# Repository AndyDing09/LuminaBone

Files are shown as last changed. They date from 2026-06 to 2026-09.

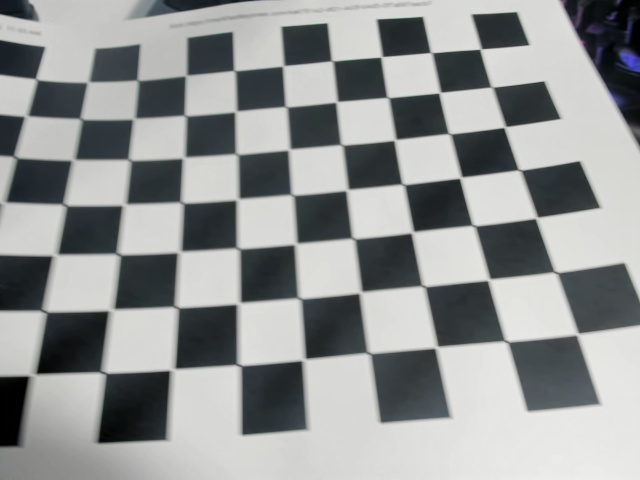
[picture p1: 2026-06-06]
calibration/calib_images/calib_034.jpg

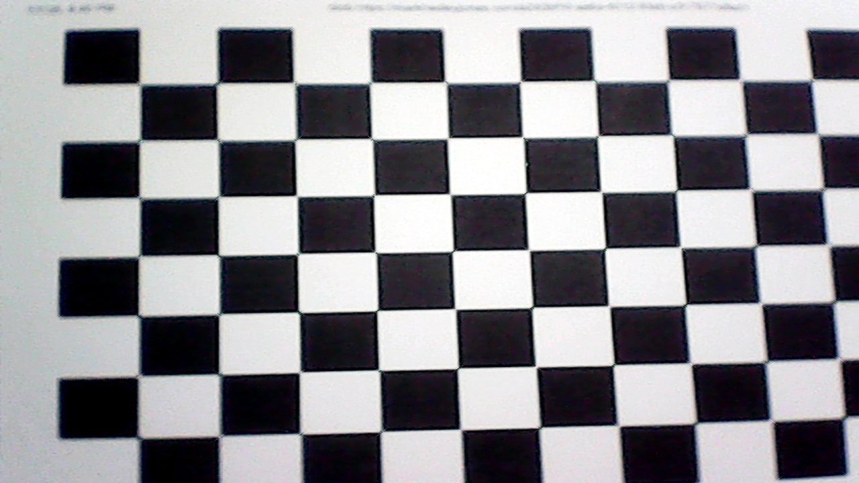
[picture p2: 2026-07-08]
calibration/calib_images_1280x720/calib_1280x720_20260707_221627_039.jpg

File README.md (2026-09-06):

# LuminaBone

Endoscope-based bone reconstruction and validation against CT ground truth,
using retroreflective marker tracking for depth/positioning.

## Status (marker-pipeline branch)

This branch is exploratory/diagnostic — several results are flagged
unreliable and documented as such rather than hidden. Read this before
trusting any numbers:

- **Reliable:** marker pixel-coordinate detection (all shots); marker
  distance from lens for shot_011 (CT + PnP ground truth).
- **Not reliable:** far-field photometric depth (`marker_depth_slides.py`)
  — inverted vs. CT at shot_011 (corr −0.92); everything downstream of it
  for shots 10/12/13/14/15 inherits that inversion.
- **Built but blocked:** near-field Lambertian depth solver
  (`nearfield_lambertian.py`) and LED calibration (`led_calibration.py`) —
  the physically-correct depth path, waiting on mirror-ball/white-card
  calibration captures that don't exist yet.
- **Registration (endoscope patches vs. CT spine):** automatic
  similarity-ICP registration of 17 reconstructed patches does **not**
  correctly localize them — patches drape onto the same region rather than
  spreading to their true anatomical sites, so the ~1.9 mm "accuracy"
  figure is an artifact, not a real accuracy measurement. A valid study
  needs landmark correspondences or fiducial markers.

## Repo layout

- `marker_pipeline/` — tracker detection → marker depth → CT-distance
  scripts, with a detailed status table in its own README.
- `registration/` — endoscope-to-CT ICP registration, accuracy report,
  and Slicer/photogrammetry helpers.
- `scripts/` — shared `calibration/`, `experiments/`, and `reconstruction/`
  code (e.g. `bone_depth_batch.py`, the far-field core dependency).
- `presentations/` — triangulation slide deck (PDF/PPTX).
- `viewer_checks/` — sanity-check renders of reconstructed models.
- `tools/` — misc utilities (e.g. `rclone.exe`).

## Open next steps

1. Capture LED calibration targets (mirror ball + matte white card) to
   unblock the near-field depth solver.
2. Resolve focal length ambiguity (fx 519 vs. 794) to remove the ~1.5×
   depth-scale uncertainty.
3. Add landmark or fiducial-based anchoring so endoscope-vs-CT accuracy
   can be measured honestly instead of via drape-fitting ICP.

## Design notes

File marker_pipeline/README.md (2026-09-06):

# marker_pipeline

Everything from the tracker → marker-depth → CT-distance work, grouped in one
place. Read the **status** column first: it says what you can trust.

## TL;DR — what is actually reliable

| Result | Trust it? |
|---|---|
| Marker **pixel coordinates** (all shots) | ✅ Yes — direct detection |
| Marker **distance from lens, shot_011** | ✅ Yes — CT ground truth + PnP (4≈33, 1≈51, 3≈53 mm*) |
| Marker **relative depth** (`marker_depth_slides`) | ❌ No — far-field model, came out **inverted** vs CT at shot_011 |
| Marker **distance, shots 10/12/13/14/15** | ❌ No — photometric only, no CT to validate (inherits the inversion) |

\* absolute values carry a ~1.5× uncertainty because the focal length is still unresolved (fx 519 vs 794).

**Only shot_011 has CT, and there the far-field depth is inverted.** So the depth
numbers are for locating/plotting markers, not for trustworthy depth. The real
depth fix (near-field solve) is built but **blocked on calibration captures**.

## Files — used vs. not

| File | Does | Status |
|---|---|---|
| `detect_trackers.py` | Finds the retroreflective markers, per image + consolidated per shot | ✅ **USED, reliable** |
| `marker_depth_slides.py` | Per-shot far-field photometric depth + the triangulation-style slides with (x,y,z) | ⚠️ **USED for x,y + slides; depth is far-field & inverted** |
| `marker_distances.py` | Lens-to-marker distance: CT+PnP for shot_011, photometric (flagged) for the rest | ✅ **USED** (shot_011 reliable; rest flagged UNRELIABLE) |
| `apply_ct_shot011.py` | Anchors shot_011 depth to CT; **documents** that the far-field depth is inverted | ⚠️ **USED as a diagnostic**, not a trustworthy correction |
| `ct_correct_depth.py` | Affine-z / tilt-plane correction helpers (self-test passes) | ✅ tool reliable; its *input* (far-field depth) is the weak link |
| `led_calibration.py` | Quéau et al. 2017 LED calibration (position/direction/µ/intensity) | 🚧 **BUILT, NOT USED** — needs mirror-ball + white-card captures that don't exist yet |

### Shared infrastructure (NOT moved — lives in `../scripts/reconstruction/`)
| File | Role | Status |
|---|---|---|
| `bone_depth_batch.py` | Far-field photometric-stereo core + image/calibration helpers | dependency (has its own pre-existing uncommitted edits) |
| `nearfield_lambertian.py` | Near-field solver; **upgraded this session to require a solved `led_calibration.json`** (no assumed geometry) | 🚧 **the intended real depth path**, blocked until calibration exists |

## How to reproduce (run order)

```bash
# from marker_pipeline/
python detect_trackers.py ../Data_collection/shots/shot_*/led*.png \
       --outdir ../tracker_outputs --csv ../tracker_outputs/trackers.csv
python marker_depth_slides.py                 # per-shot depth slides + marker_depths.csv
python marker_distances.py                    # lens-to-marker distances (shots 10-15)
python apply_ct_shot011.py                    # shot_011 CT anchor (diagnostic)

# validation (no data needed):
python ct_correct_depth.py --selftest
python led_calibration.py  --selftest
```

Outputs land in `../depth_outputs/marker_depth_slides/` and `../tracker_outputs/`.

## The one path to trustworthy depth (currently blocked)
1. Capture calibration targets: a **mirror ball** (~10 poses/LED) and a **matte
   white card** (~3–5 tilts/LED).
2. `led_calibration.py` → writes `calibration/led_calibration.json`.
3. `nearfield_lambertian.py` re-solves depth with the real light model (no bowl,
   no inversion).
4. Anchor the result to CT with `ct_correct_depth.py`.

Also worth doing: resolve the focal length (photograph a known-size object at a
known distance) to kill the 1.5× absolute-scale ambiguity.

## Key caveats discovered
- **CT is in the CT scanner's frame, not the camera frame** — you must PnP-align
  before comparing depth. Raw-axis comparison is meaningless.
- **P3P with 3 points is ambiguous** (up to 4 poses); we disambiguate with the
  confirmed physical fact that *marker 4 is closest*.
- With that pose, the far-field photometric depth is **anti-correlated with CT
  (corr −0.92)** at shot_011 — i.e. inverted. That is the headline finding.

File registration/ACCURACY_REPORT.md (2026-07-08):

# Endoscope-vs-CT accuracy: what the registration actually shows

## What I did
Registered all 17 endoscope reconstructions (`loc01–17`) to the CT spine
(`ct_spine.stl`, a lumbar+sacrum segment, mm coordinates) using automatic
similarity ICP (rotation + translation + uniform scale), with centroid
initialization, a realistic scale prior, and rotation restarts. Outputs are in
`reg_out/`: each aligned patch, a combined model (`combined_CT_plus_17.ply`),
per-patch metrics (`accuracy_summary.csv`), and the overlay (`accuracy_overlay.png`).

## The honest result: automatic registration did NOT place the patches correctly
- **12 of 17** patches got a plausible scale (~0.07 mm/px) and ~1.9 mm median
  surface distance — which *looks* like a good accuracy number.
- **But the overlay shows they all piled onto the same region of the bone**,
  stacked as flat cards, instead of spreading to the 17 different spots where the
  photos were actually taken. So the low distance is a **draping artifact**: a
  bumpy patch laid flat against a bumpy surface always sits ~2 mm off, *wherever*
  you put it. It is not a measure of reconstruction accuracy.
- **5 of 17** (loc07, 09, 10, 11, 14) collapsed to scale ≈ 0 — the scale-ICP
  shrank the patch to a point to trivially minimise distance. Flagged SUSPECT.

The uniformity is the tell: median deviation across the 12 "OK" patches is
1.86 mm with a standard deviation of only 0.17 mm. Genuinely-registered patches
at 17 different anatomical sites would not all score the same.

## Why this happens (not fixable by better ICP)
Each endoscope view is a small, nearly-flat brightness-relief patch; the CT is a
whole 232 mm multi-vertebra segment. With no point correspondences and no known
probe pose, a flat patch can rest on many places with equally low residual, and
its scale is unconstrained. ICP therefore cannot recover the *true* location — it
finds *a* low-distance drape, not the *correct* one.

## The one real quantitative finding
The recovered scales for the 12 non-degenerate patches cluster at
**0.070 ± 0.012 mm/px**. Consistent scale across independent views is expected if
the endoscope working distance was roughly constant — a believable internal
cross-check on the reconstruction pipeline. (Note: the pipeline's own
`depth_estimates.csv` implies ~0.047 mm/px for the depth axis; the ~0.07 in-plane
value is the same order, differing because depth and in-plane were scaled
separately.)

## What a valid accuracy study needs
To actually measure "how accurate is the endoscope reconstruction vs CT," each
patch must first be correctly located on the bone. That requires one of:
1. **Matched landmarks per patch** — 3–4 corresponding points (e.g. the through-
   holes/foramina visible in both the photo and the CT). The tools here
   (`landmark_register.py` + `icp_refine.py`) compute this in closed form and
   report a real error, but placing the points needs someone who knows where each
   shot was taken.
2. **CT-visible fiducial markers** (metal beads) placed on the specimen before
   scanning, appearing in both modalities.
3. **Recorded probe poses** at capture time.

Once any patch is correctly anchored (the loc03 foramina are the best candidate),
the residual surface distance at that site becomes a *true* reconstruction-accuracy
number, and the same can be repeated for the rest.

## Files
- `reg_out/accuracy_overlay.png` — shows the piling-up problem
- `reg_out/accuracy_summary.csv` — per-patch scale, deviation, reliability
- `reg_out/combined_CT_plus_17.ply` — CT + all patches, viewable in Slicer
- `reg_out/locNN_reg.ply` — individual aligned patches

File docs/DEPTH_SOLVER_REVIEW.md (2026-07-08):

# Depth Estimate Solver Review

## Source Of Truth

The current depth estimate solver is in `bone_depth_batch.py`. The exact solve
path is:

1. `process_location()`
2. `solve_luminance()`
3. `balance_exposure()`
4. `photometric_stereo()`
5. `normals_to_depth()`
6. `integrate_frankot_chellappa()`

`bone_depth_values.py`, `depth_recompute.py`, and `make_triangulation_slides.py`
reuse that same solver. Scripts with `allon` in the name use the older
single-image brightness-to-depth approximation from `endoscope_depth.py`; those
are useful for quick colored meshes, but they are not the main three-light depth
estimate.

## Inputs

Each location is expected to have four photos:

- `pN-1`: all LEDs on, used as a visual/color reference
- `pN-2`: right LED only
- `pN-3`: upper LED only
- `pN-4`: left LED only

The depth solve uses only the three single-LED photos. The all-on photo does not
drive the photometric-stereo solve.

## Calculation Flow

First, each single-LED RGB image is converted to linear luminance. The code
undoes sRGB gamma, converts RGB to a brightness channel, removes specular glints,
and balances exposure by dividing each light image by its median brightness.
This matters because photometric stereo assumes brightness differences come from
surface orientation, not camera auto-exposure or shiny highlights.

Next, the solver builds a light-direction matrix `L`. Each row is a known unit
light vector from `SINGLE_LED_AZIMUTH_DEG` and `LIGHT_ELEVATION_DEG`.

For every pixel, the three observed brightnesses form:

```text
L @ g = I
```

where `I` is the pixel brightness under the three LEDs and `g` is the unknown
albedo-scaled normal. With three lights, the code uses an exact inverse:

```text
g = inverse(L) @ I
```

Then:

```text
albedo = norm(g)
normal = g / albedo
```

After normals are estimated, `normals_to_depth()` converts them into depth
gradients. With the repo's convention, larger depth means farther from the
camera:

```text
d(depth)/d(col) = +nx / nz
d(depth)/d(row) = -ny / nz
```

Finally, `integrate_frankot_chellappa()` solves for the depth map whose
gradients best match those two gradient fields. It does this in the frequency
domain with an FFT Poisson solve. The result is a relative depth map.

## Units

The native output is relative depth in working-resolution pixel units. The
relative relief shape is meaningful, but the absolute physical height is not
known from photometric stereo alone.

The scripts now report inch-scaled relief using:

```text
inches_per_pixel = FIELD_WIDTH_IN / image_width_px
relief_in = relief_px * inches_per_pixel
```

This is only physically correct if `FIELD_WIDTH_IN` is the measured real width
of the photographed area. The default keeps the previous 30 mm placeholder,
converted to inches, so update it before treating the inch values as true.

## Review Notes

- The main photometric-stereo math is internally consistent.
- The sign convention is depth-away-from-camera; 3D plots negate depth so bone
  protrusions point upward/toward the viewer.
- The strongest uncertainty is absolute scale. `LIGHT_ELEVATION_DEG` changes
  vertical relief, and `FIELD_WIDTH_IN` converts pixel relief to physical units.
- The `pN-3` upper light is calibrated as an upper-right light, not a pure top
  light. That is already reflected in `SINGLE_LED_AZIMUTH_DEG`.
- The older `allon` mesh scripts use a simpler inverse-square brightness model.
  Use the photometric-stereo outputs for the best available depth relief.

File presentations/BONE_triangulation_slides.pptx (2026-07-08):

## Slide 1

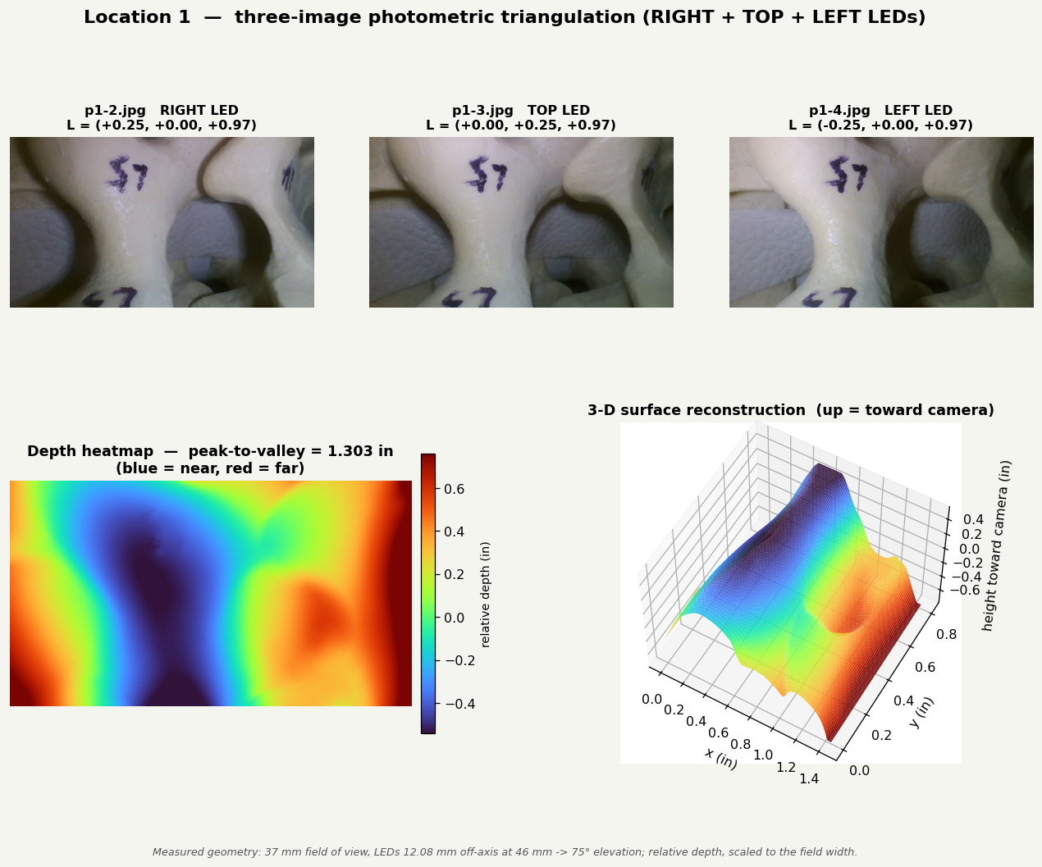
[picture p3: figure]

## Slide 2

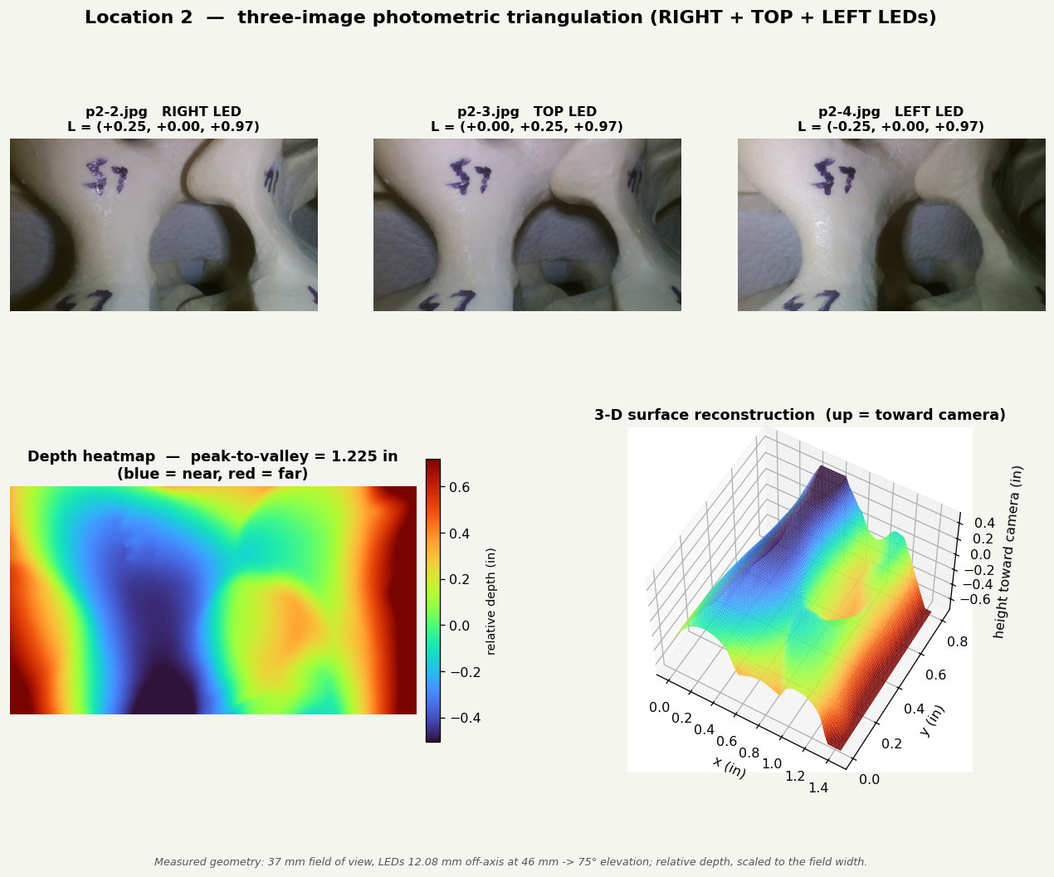
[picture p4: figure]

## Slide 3

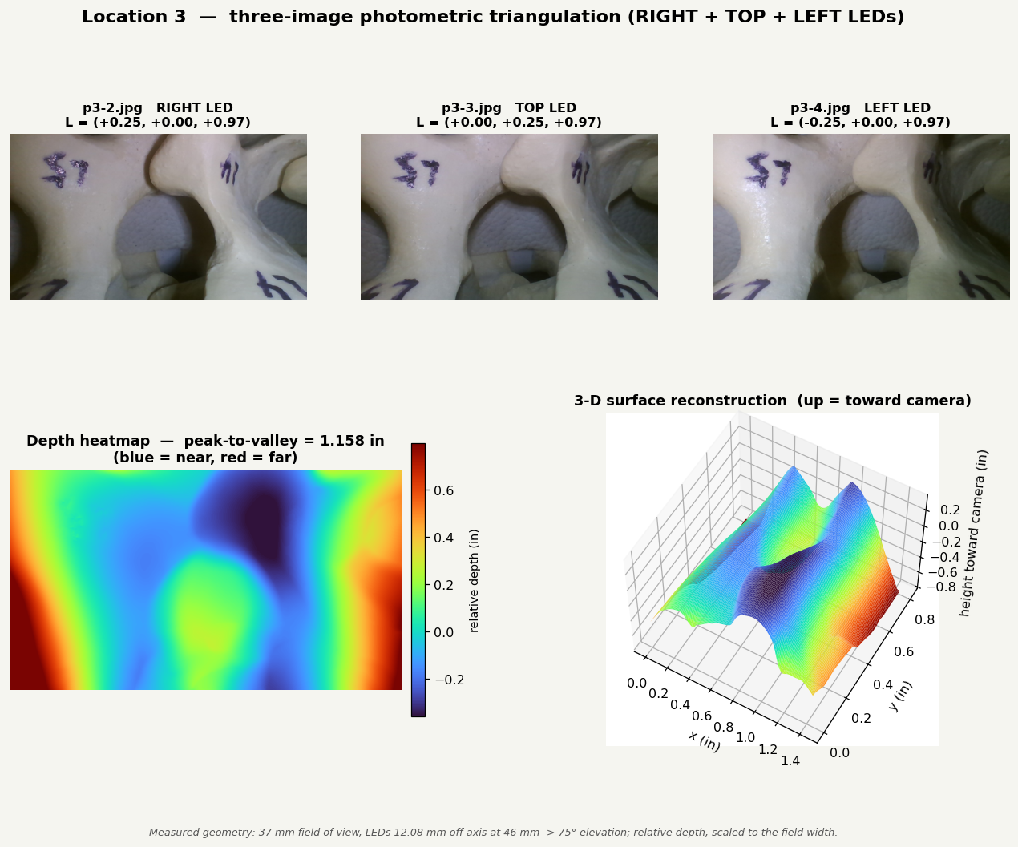
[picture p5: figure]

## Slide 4

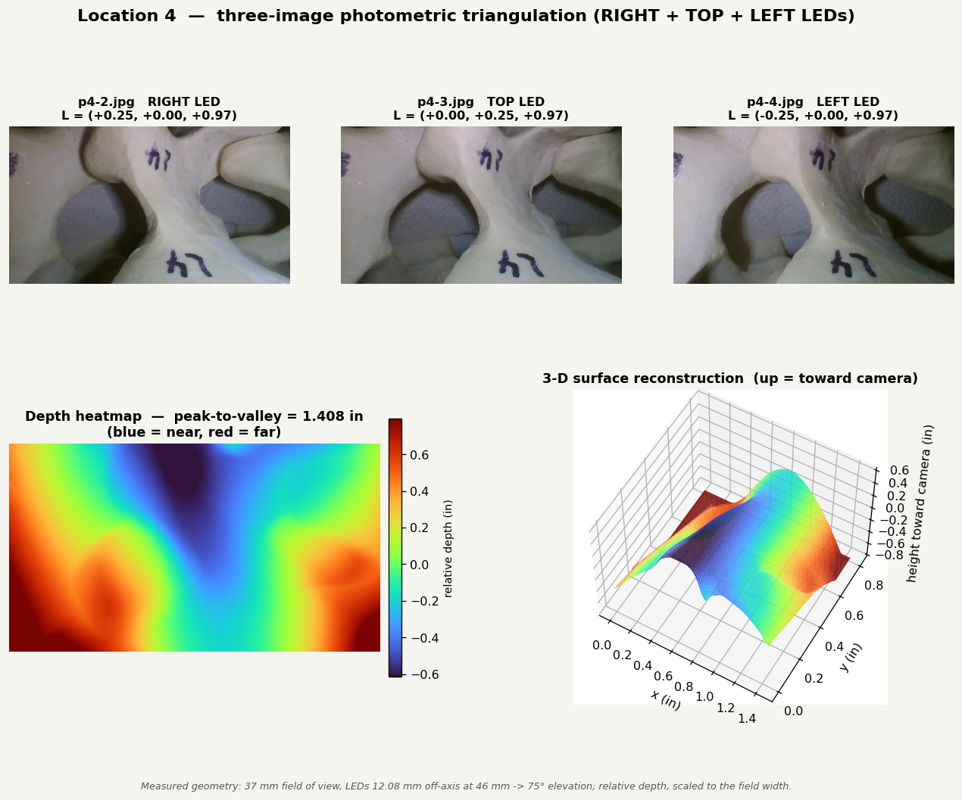
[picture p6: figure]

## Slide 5

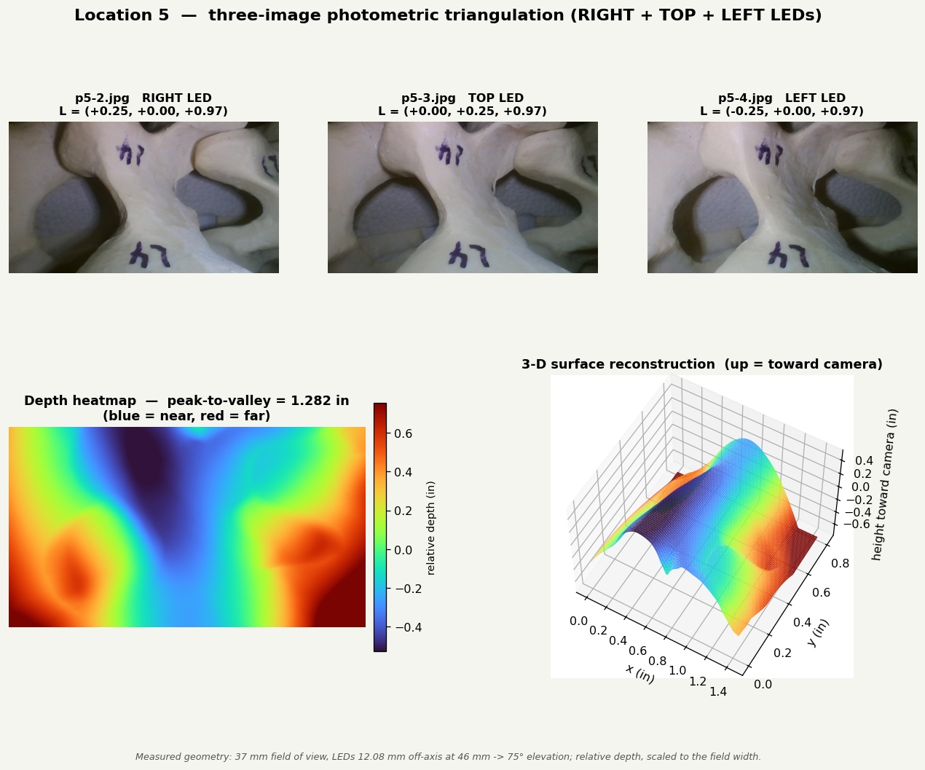
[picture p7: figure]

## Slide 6

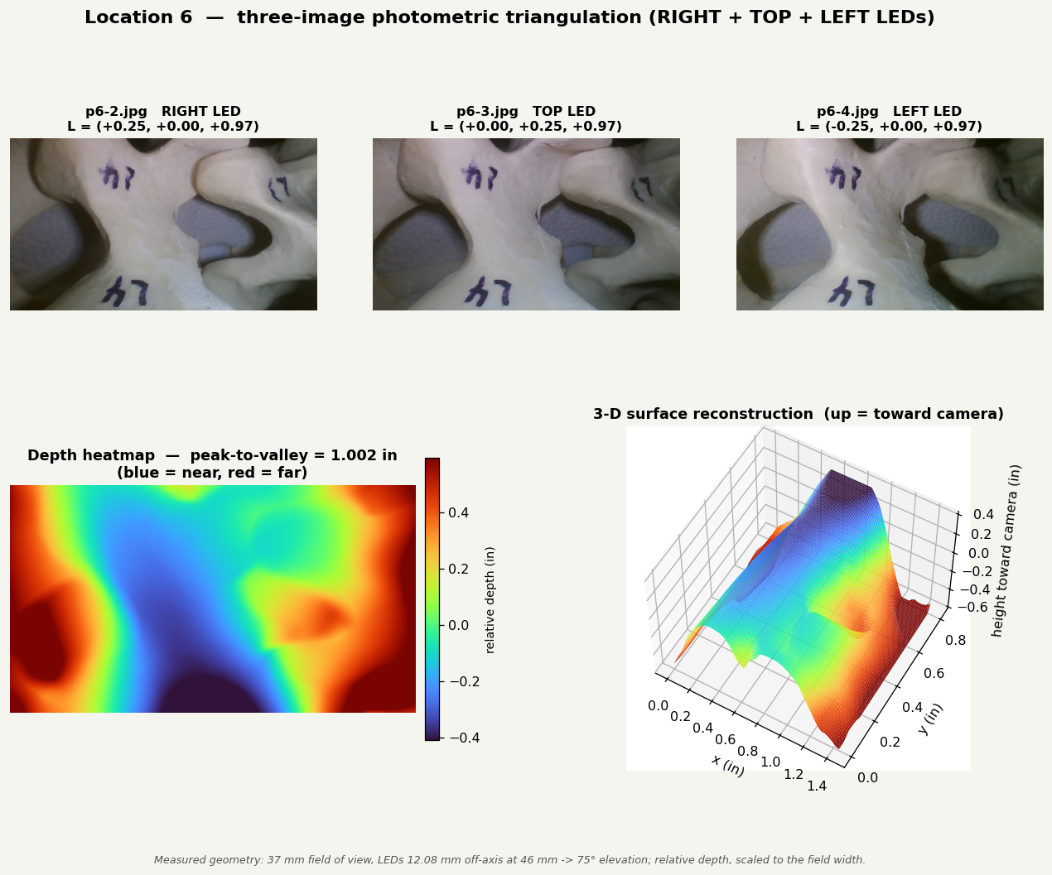
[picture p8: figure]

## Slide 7

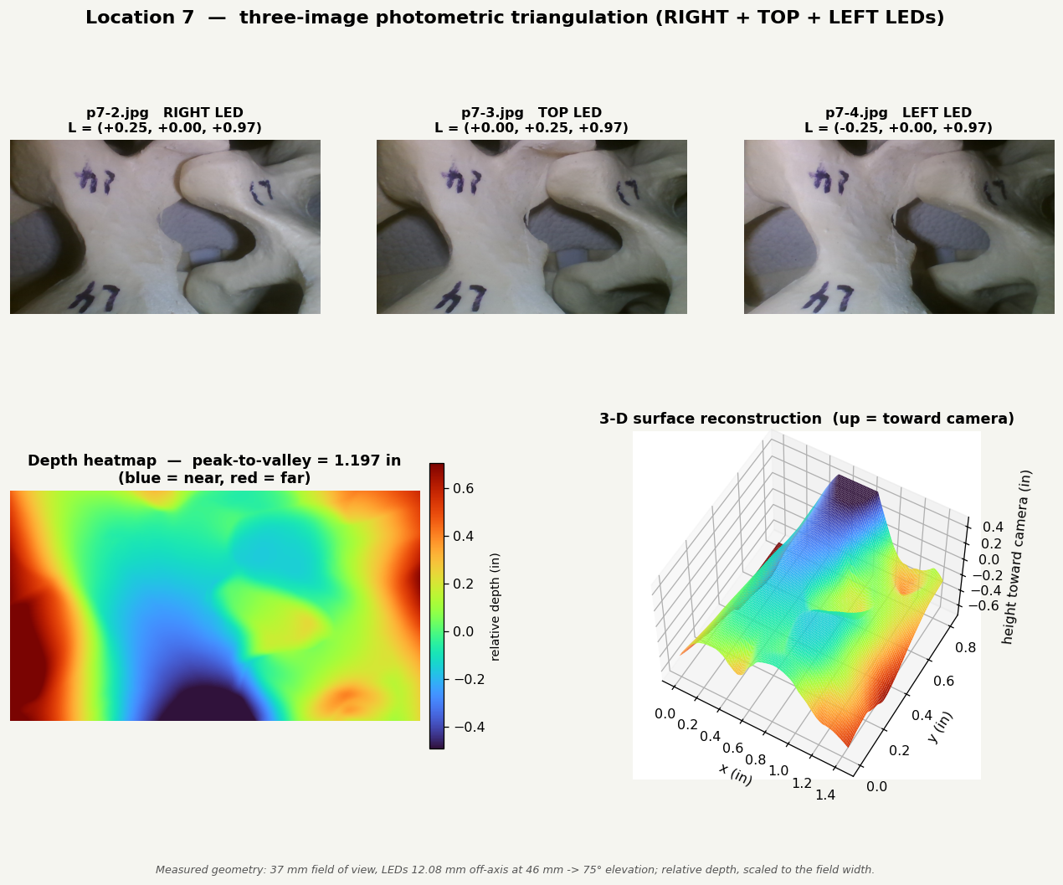
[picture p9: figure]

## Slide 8

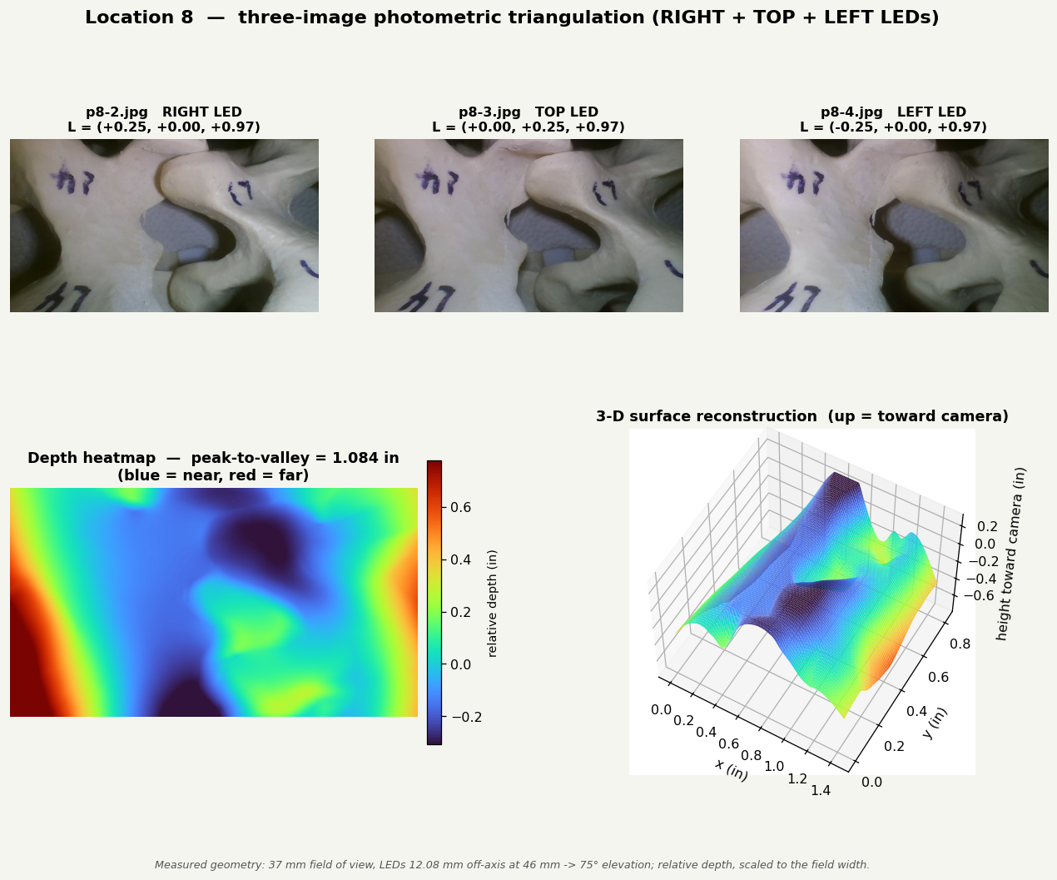
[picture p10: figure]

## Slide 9

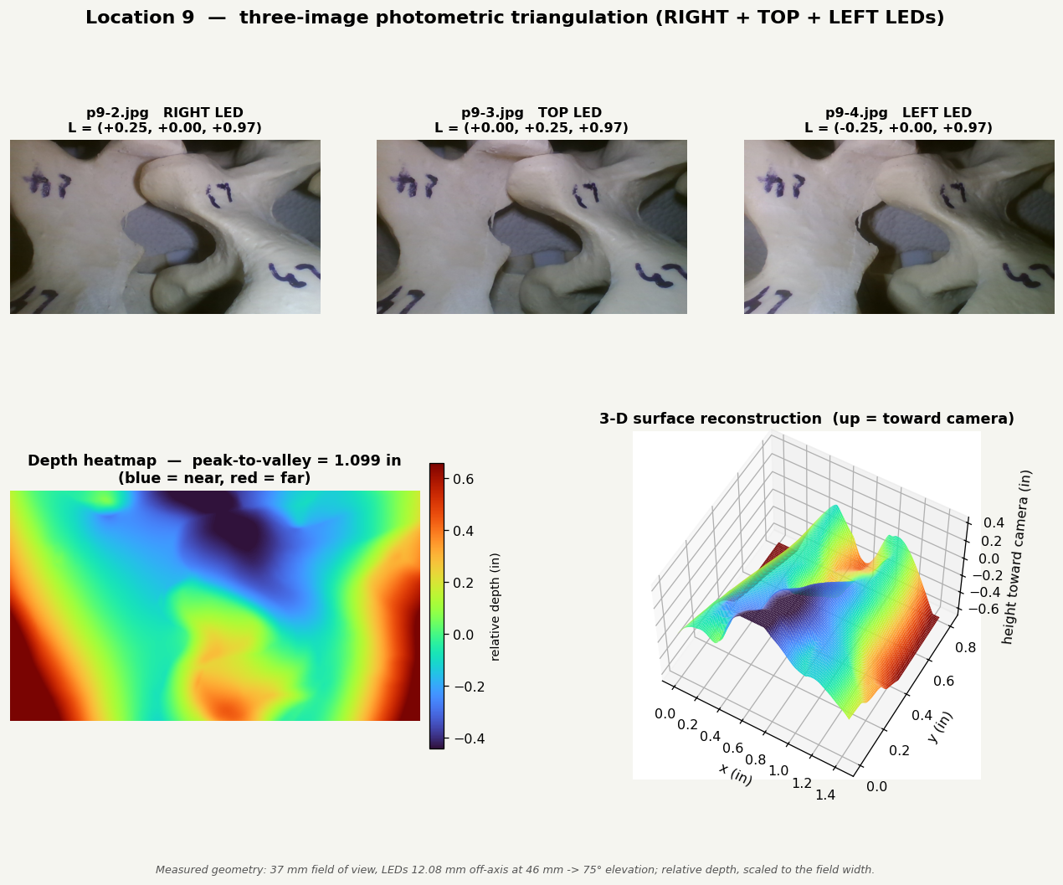
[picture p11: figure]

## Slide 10

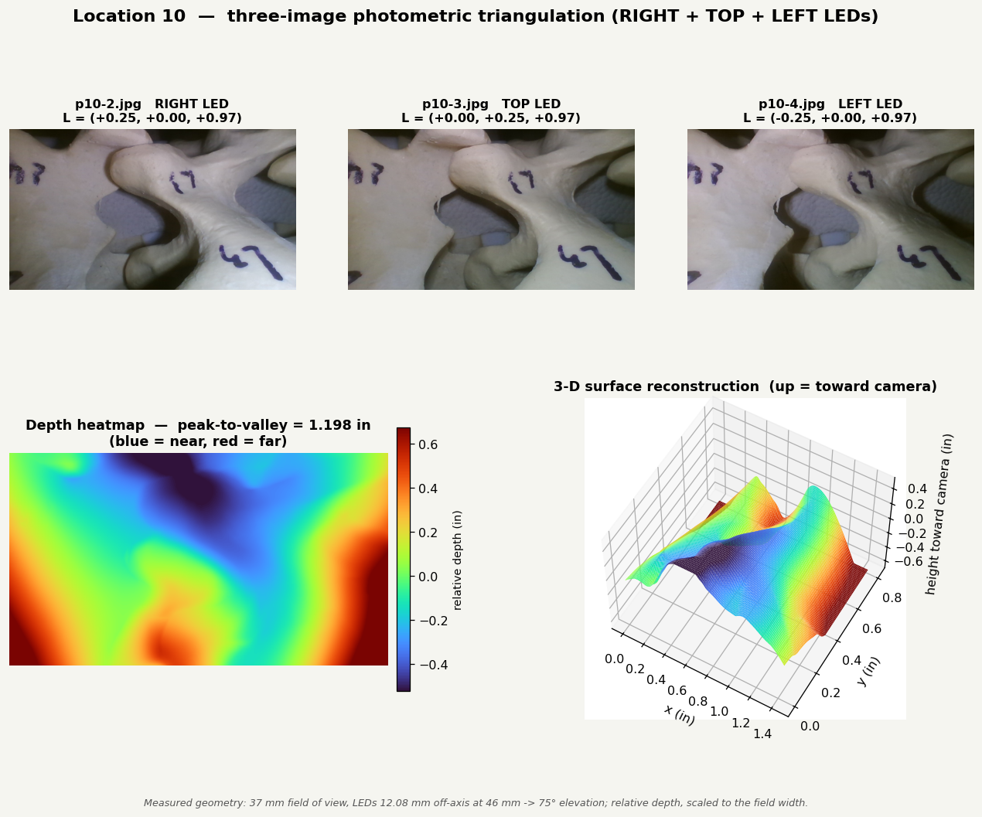
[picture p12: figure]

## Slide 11

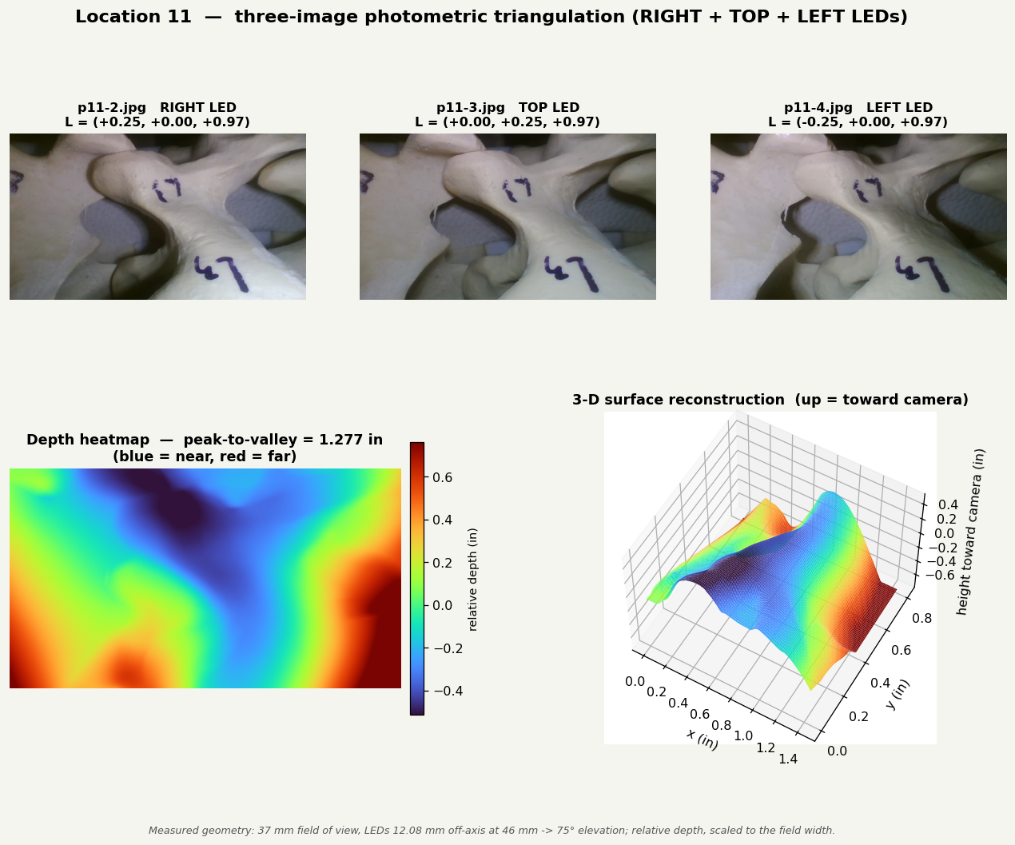
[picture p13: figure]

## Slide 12

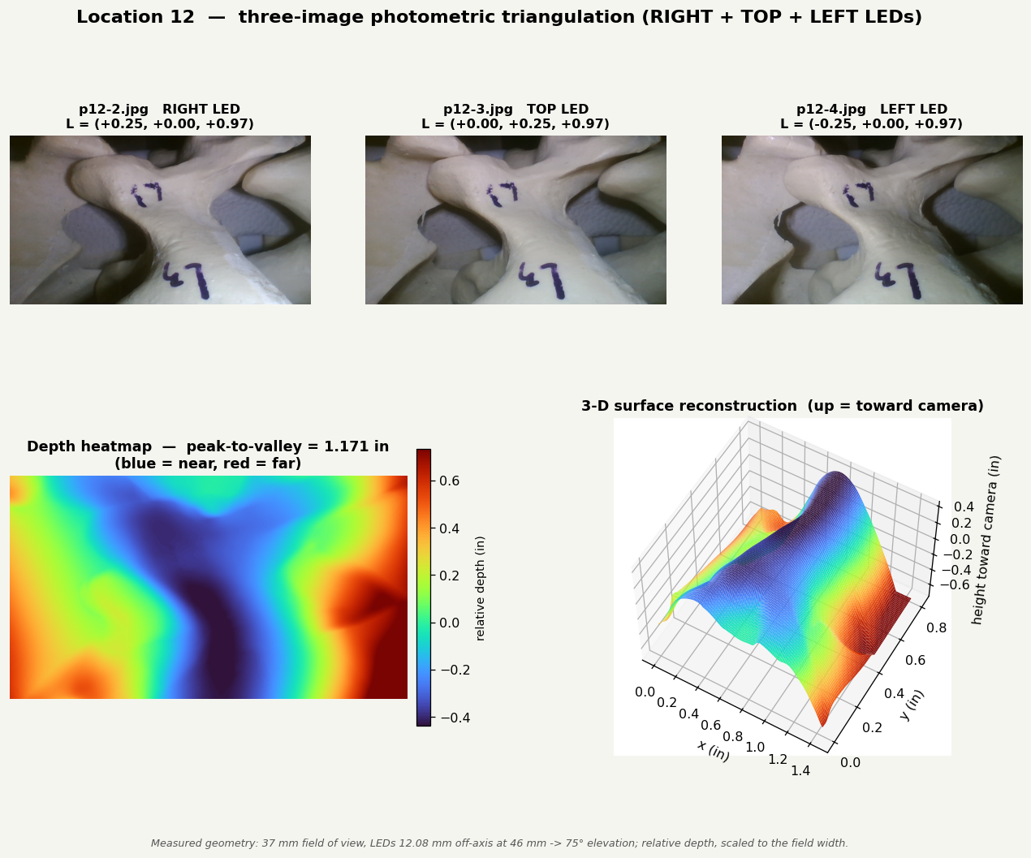
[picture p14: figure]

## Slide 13

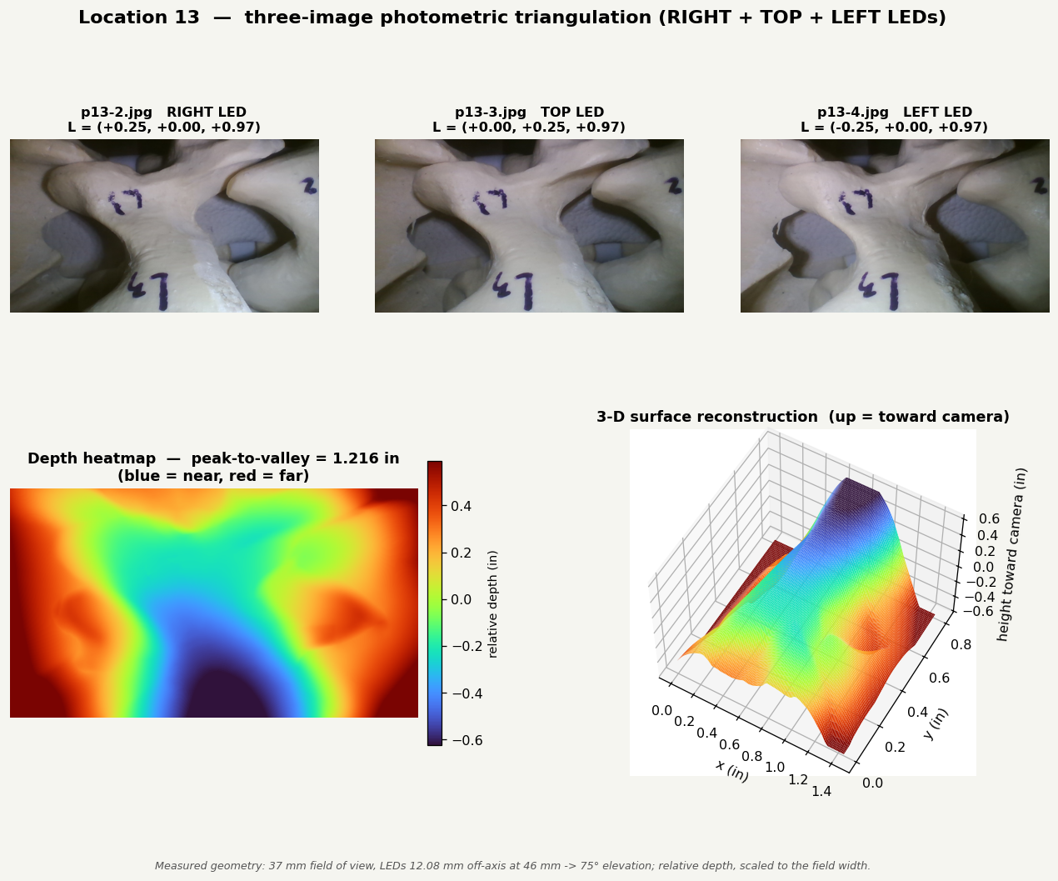
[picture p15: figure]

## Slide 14

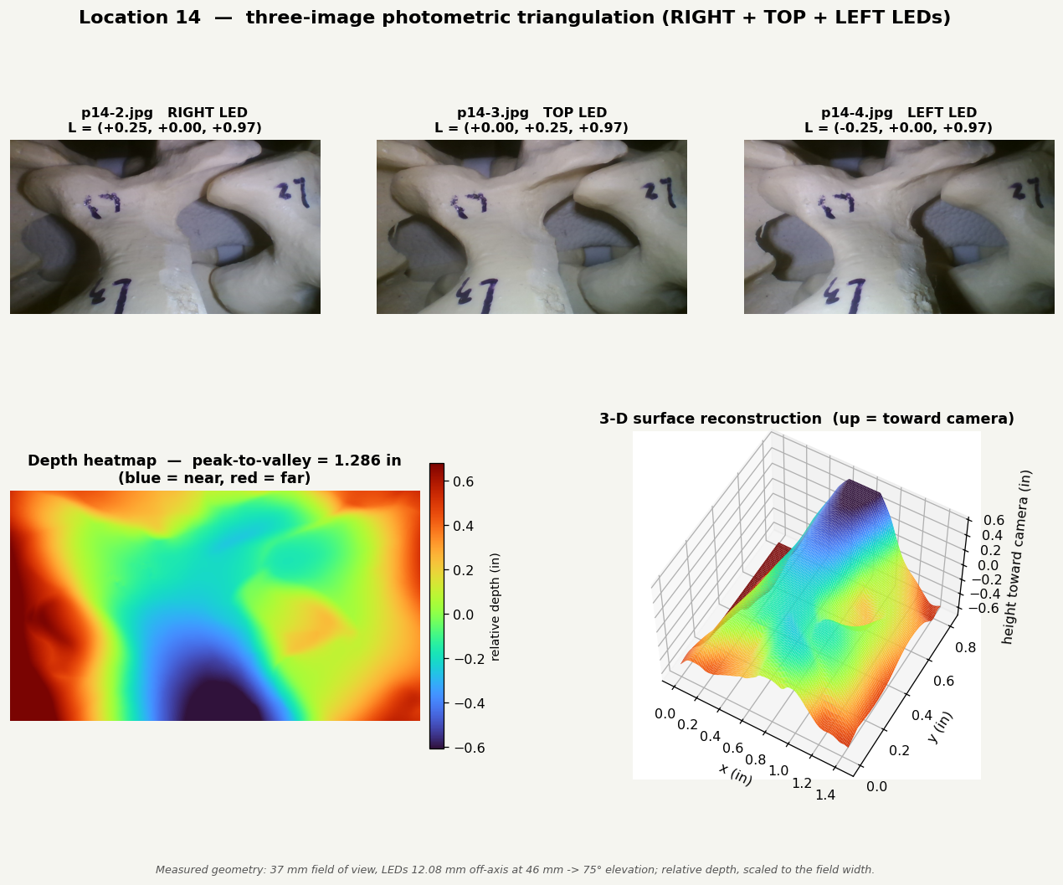
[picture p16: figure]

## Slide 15

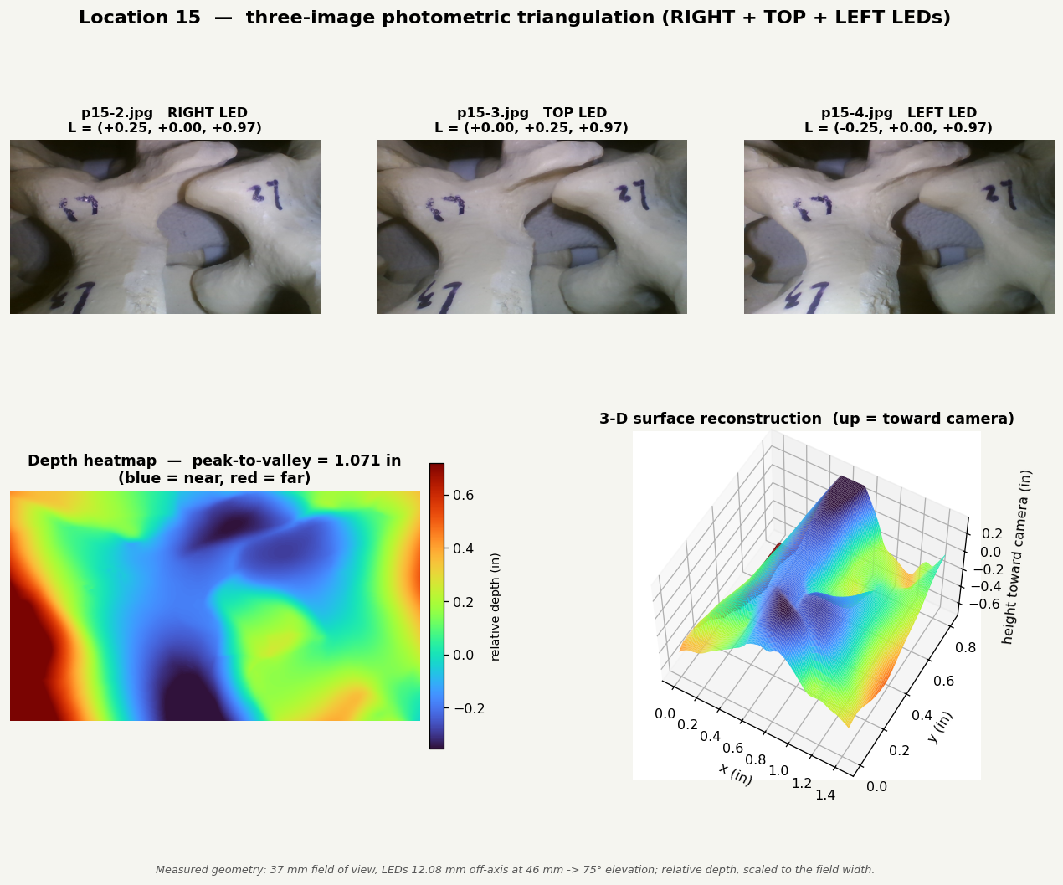
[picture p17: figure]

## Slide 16

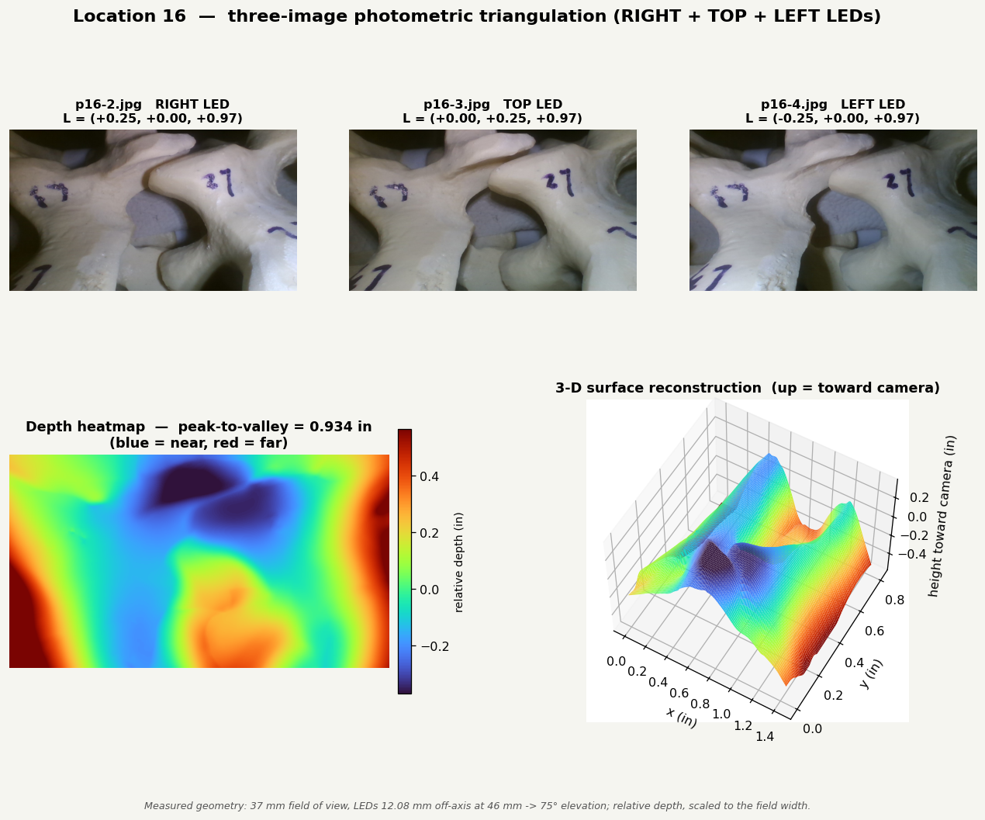
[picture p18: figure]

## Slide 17

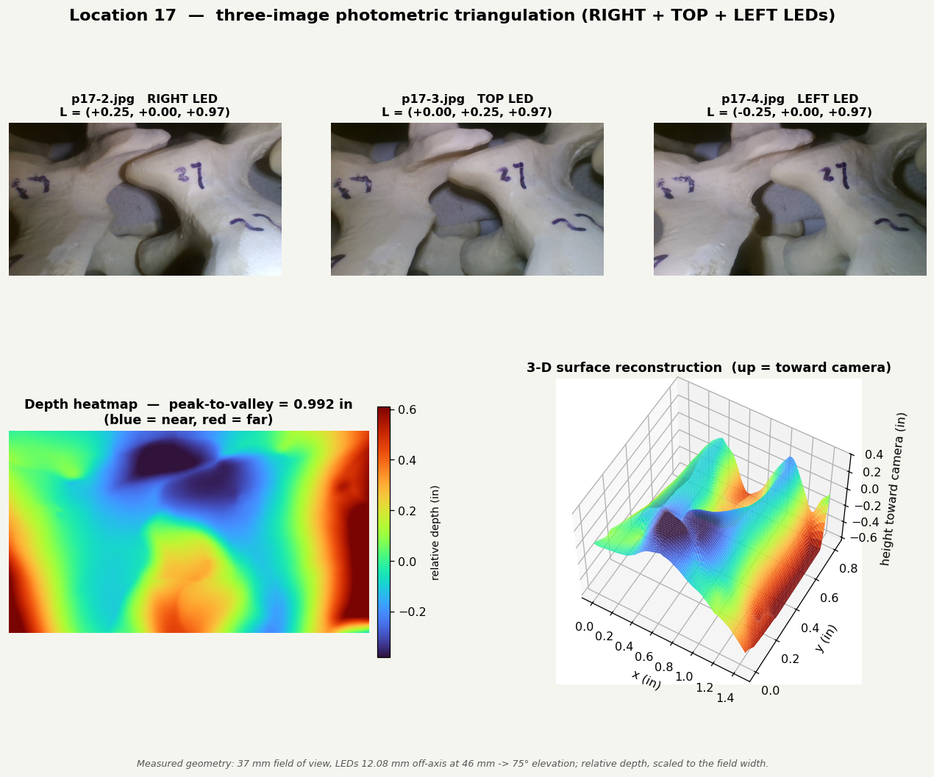
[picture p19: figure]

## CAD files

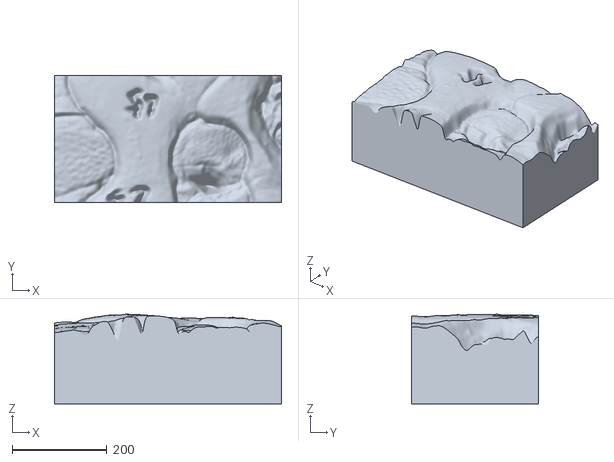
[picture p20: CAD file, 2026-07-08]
depth_outputs/loc01_solid.ply
479.0 x 269.0 x 189.2

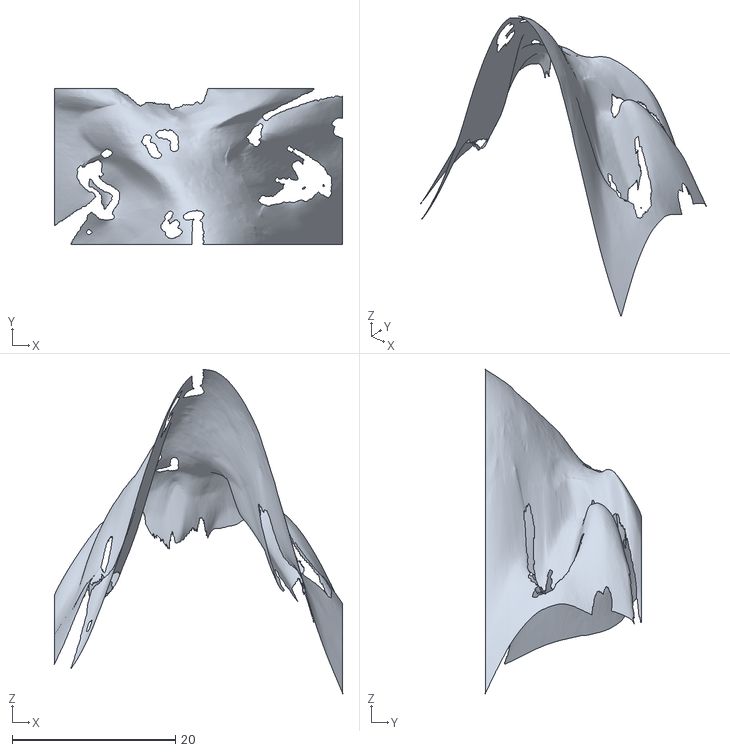
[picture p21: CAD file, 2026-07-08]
depth_outputs/meshes/loc13_mesh.ply
35.4 x 19.2 x 39.7

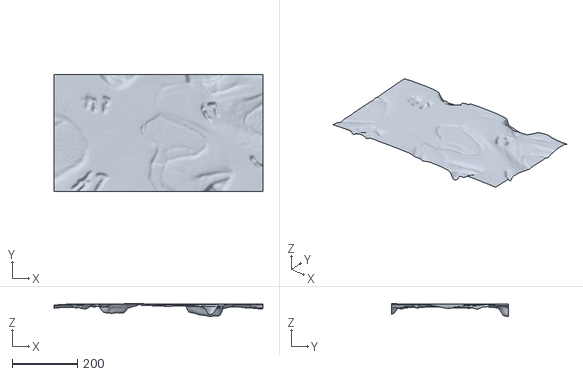
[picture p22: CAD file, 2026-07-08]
depth_outputs/ply_allon_mesh/loc08_allon_mesh.ply
639.0 x 359.0 x 39.1

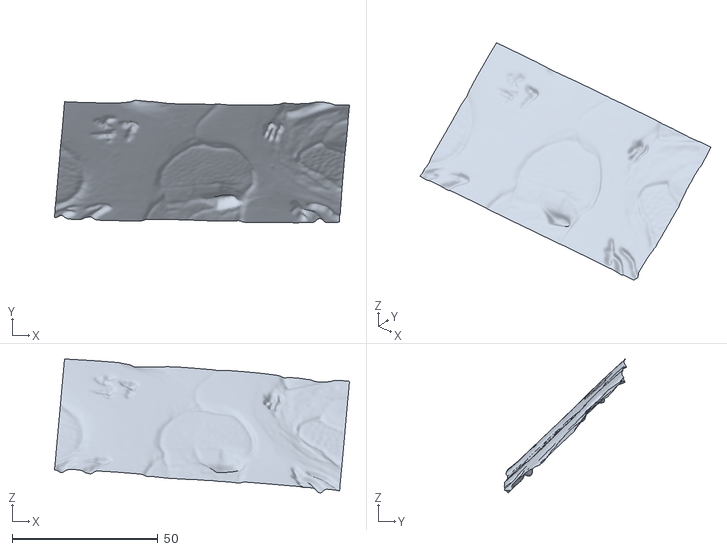
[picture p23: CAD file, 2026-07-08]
registration/endo_registered_in_slicer.ply
101.1 x 42.0 x 45.8

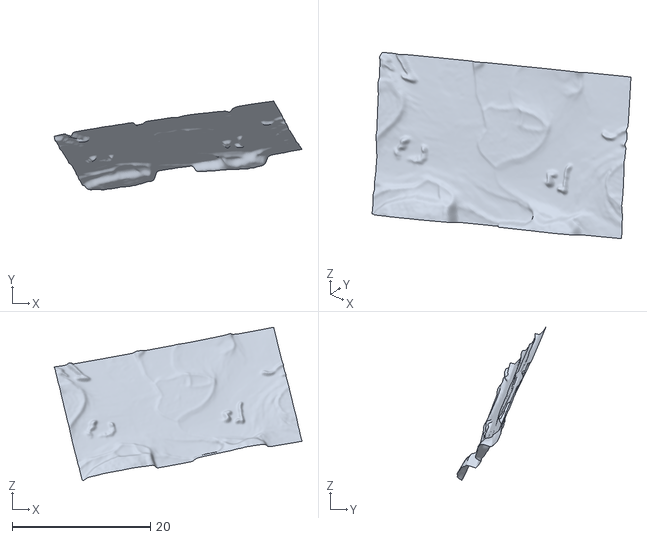
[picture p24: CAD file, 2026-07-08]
registration/reg_out/loc16_reg.ply
35.8 x 12.8 x 22.2

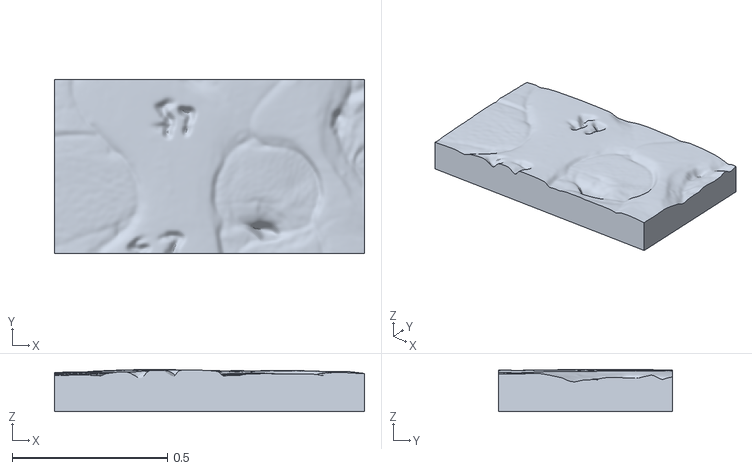
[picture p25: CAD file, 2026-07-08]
depth_outputs/loc01_solid_in.ply
0.998 x 0.56 x 0.135

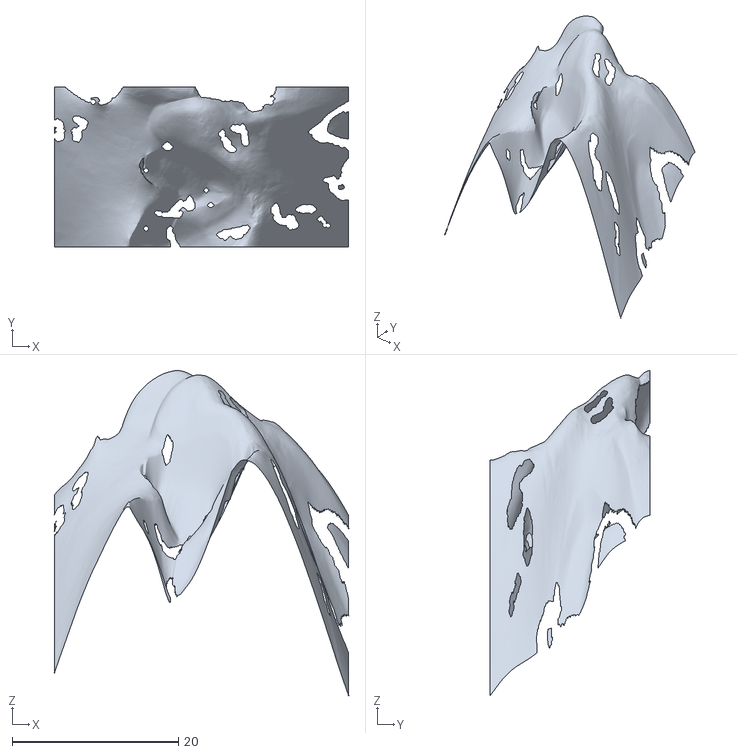
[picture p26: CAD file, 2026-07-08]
depth_outputs/meshes/loc10_mesh.ply
35.4 x 19.2 x 39.1

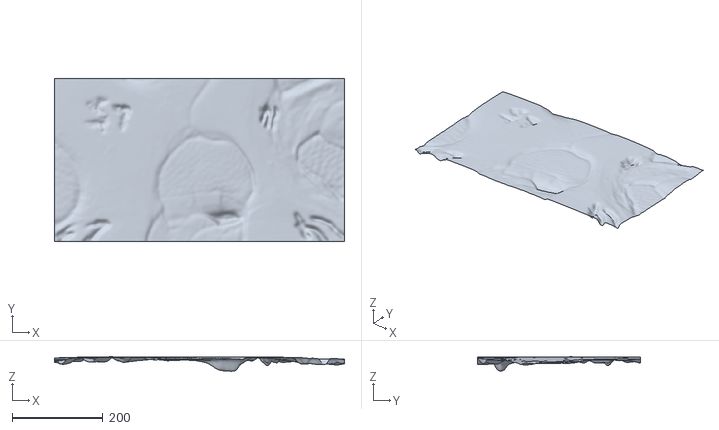
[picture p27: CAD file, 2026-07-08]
depth_outputs/ply_allon_mesh/loc03_allon_mesh.ply
639.0 x 359.0 x 32.0

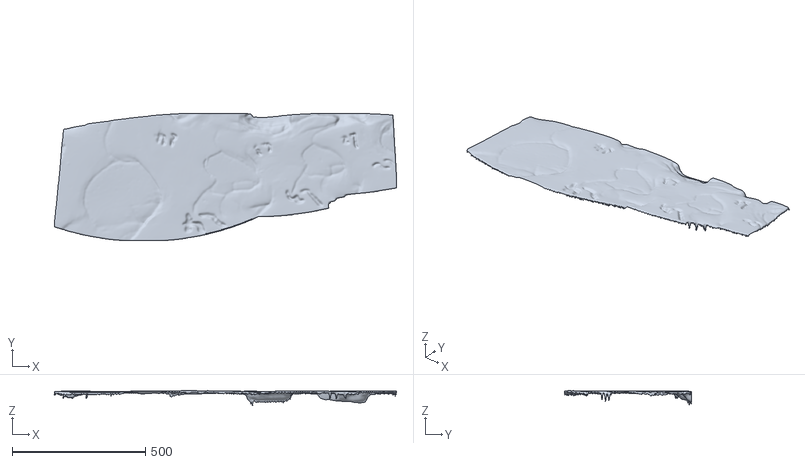
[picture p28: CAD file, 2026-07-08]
depth_outputs/stitched/spine_stitched_mesh.ply
1281.0 x 475.0 x 54.6

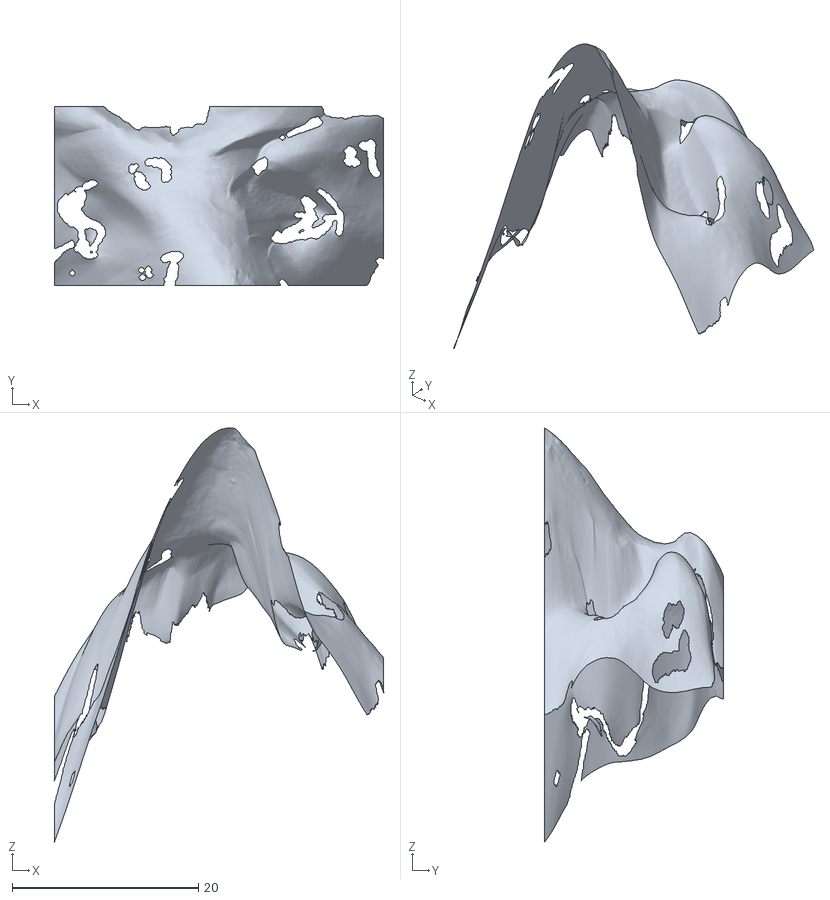
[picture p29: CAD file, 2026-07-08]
depth_outputs/meshes/loc14_mesh.ply
35.4 x 19.2 x 44.5

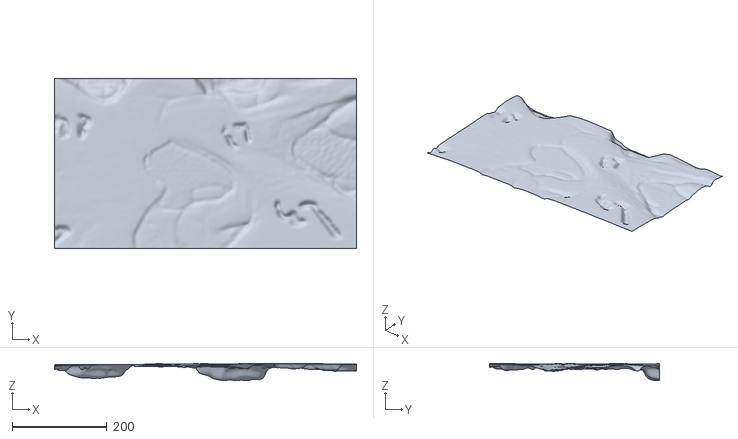
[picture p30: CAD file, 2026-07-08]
depth_outputs/ply_allon_mesh/loc10_allon_mesh.ply
639.0 x 359.0 x 36.2

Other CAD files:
depth_outputs/ply_allon/loc01_allon.ply
depth_outputs/stitched/spine_stitched_cloud.ply
outputs/paper_endoscope_c.ply
depth_outputs/ply_allon/loc14_allon.ply
outputs/paper_endoscope_a.ply
registration/reg_out/loc10_reg.ply
depth_outputs/ply_allon/loc06_allon.ply
depth_outputs/meshes/combined_surface.ply
depth_outputs/meshes/combined_surface_points.ply
depth_outputs/meshes/loc01_mesh.ply
depth_outputs/meshes/loc02_mesh.ply
depth_outputs/meshes/loc03_mesh.ply
depth_outputs/meshes/loc04_mesh.ply
depth_outputs/meshes/loc05_mesh.ply
depth_outputs/meshes/loc06_mesh.ply
depth_outputs/meshes/loc07_mesh.ply
depth_outputs/meshes/loc08_mesh.ply
depth_outputs/meshes/loc09_mesh.ply
depth_outputs/meshes/loc11_mesh.ply
depth_outputs/meshes/loc12_mesh.ply
depth_outputs/meshes/loc15_mesh.ply
depth_outputs/meshes/loc16_mesh.ply
depth_outputs/meshes/loc17_mesh.ply
depth_outputs/ply_allon/loc02_allon.ply
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

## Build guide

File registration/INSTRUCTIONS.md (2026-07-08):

# Landmark registration — endoscope cloud → CT spine model

Method: closed-form **similarity** (rigid rotation + translation + one uniform
scale) from matched fiducial pairs (Umeyama/Horn). Gives an exact, honest
**fiducial registration error (FRE)** in millimetres and — because the endoscope
depth is only *relative* — recovers the missing metric scale from the CT.

## Why landmarks and not automatic ICP
The endoscope clouds are near-planar brightness-relief patches (depth std ≈ 4 px
vs 640×360 in-plane). Surface ICP onto a curved vertebra is under-constrained and
returns confident-but-arbitrary poses. Matched landmarks remove that ambiguity.

## What you do in 3D Slicer (one time)

1. **Export the CT bone surface**
   - Segment the vertebra (Segment Editor) → *Segmentation* module →
     *Export to files* → STL (or right-click the model → Export).
   - Save it into this `registration/` folder, e.g. `ct_spine.stl`.

2. **Load the endoscope cloud** you want to register
   - File → Add Data → pick one `depth_outputs/ply_allon/locNN_allon.ply`
     (it loads as a Model, with its photo colour). Start with a location that
     covers a **curved / featured** region, not a flat face.

3. **Place matched fiducials (same real point on each, same order)**
   - Markups module → create a point list named **`source`** → click 4–8 clearly
     identifiable features **on the endoscope model** (foramen edge, a ridge, a
     corner, a vessel groove…).
   - Create a second list named **`target`** → click the **same physical points,
     in the same order**, on the CT model.
   - **Important:** don't put all points on a single flat patch — include points
     at different depths so out-of-plane orientation is constrained. Aim for ≥4,
     ideally 6+.
   - Save each list: right-click → *Export* (or File → Save) as
     `source.mrk.json` and `target.mrk.json` into this folder.
   - `.fcsv` or a plain `x,y,z` CSV also work.

## Then I run (or you can run):

```
python landmark_register.py \
    --source-fids registration/source.mrk.json \
    --target-fids registration/target.mrk.json \
    --cloud       depth_outputs/ply_allon/locNN_allon.ply \
    --outdir      registration/reg_out
```

### Optional stage 2 — ICP surface refinement
After the landmark alignment, tighten the fit against the full CT surface:

```
python icp_refine.py \
    --source registration/reg_out/locNN_allon_registered.ply \
    --target registration/ct_spine.stl \
    --outdir registration/reg_out --trim 0.8
```
Point-to-plane, trimmed (rejects the non-overlapping part of the vertebra as
outliers). It only *refines* — it cannot fix a bad landmark start, and on a flat
patch it can slide in-plane, so keep the landmark FRE as the primary trust metric
and eyeball the overlay. Add `--with-scale` only if you want ICP to nudge scale too.

Outputs land in `registration/reg_out/`:
- `locNN_allon_registered.ply` — the cloud moved into CT space (load in Slicer, it
  drops onto the bone; no transform juggling needed).
- `transform_source_to_target.txt` / `.npy` — the 4×4 matrix + recovered scale.
- `transform_itk.tfm` — import via Slicer → Transforms if you'd rather keep the
  original cloud and apply a transform node.
- `registration_report.json` — recovered **scale**, **FRE rms/max**, per-landmark
  residuals, and a near-planar conditioning warning.

## Reading the result
- **FRE rms** ≈ how well the points line up (mm). With careful picking on a
  featured region expect low single-digit mm; large values mean mismatched or
  coplanar points.
- **scale** is the recovered mm-per-cloud-unit. Cross-check: the pipeline's own
  `depth_estimates.csv` implies ≈0.046875 mm/px for Z only — X/Y are raw pixels,
  so the landmark scale tells you the true in-plane mm/px.
- **near_planar_warning = true** → add landmarks with more depth variation.

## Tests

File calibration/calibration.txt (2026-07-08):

{
  "camera_matrix": [
    [
      1587.9838343574543,
      0.0,
      646.3018190391646
    ],
    [
      0.0,
      1194.2225409787034,
      339.6362448973934
    ],
    [
      0.0,
      0.0,
      1.0
    ]
  ],
  "dist_coeffs": [
    [
      0.13490056551012142,
      -0.41856699112495277,
      -0.0038193583132642497,
      0.0017845237107306754,
      -2.5471458381780363
    ]
  ],
  "image_size": [
    1280,
    720
  ],
  "reprojection_error": 0.10696129323542458,
  "num_images_used": 51
}

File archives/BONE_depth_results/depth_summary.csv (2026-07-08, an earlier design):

location | width | height | n_lights | azimuths_deg | depth_min | depth_max | depth_mean | depth_std | relief_p2_p98
1 | 640 | 360 | 3 | 0;90;180 | -42.807458520177164 | 30.38262288345302 | -1.7171449447535754e-16 | 19.349500692961456 | 64.48463917831536
2 | 640 | 360 | 3 | 0;90;180 | -42.34485921598966 | 24.488499740583443 | 1.0559454545323711e-16 | 17.674066092678952 | 61.27786891905254
3 | 640 | 360 | 3 | 0;90;180 | -44.69595626779325 | 23.58860699005741 | 8.585724723767877e-17 | 15.58635057184014 | 59.18601328825106
4 | 640 | 360 | 3 | 0;90;180 | -35.4608597481478 | 29.91023681274014 | 2.565848768022584e-17 | 17.554924437459885 | 57.88457877083153
5 | 640 | 360 | 3 | 0;90;180 | -37.73514705458908 | 27.513284557761633 | 5.013273746751818e-16 | 17.73254831582852 | 56.93774502921187
6 | 640 | 360 | 3 | 0;90;180 | -37.79224890586219 | 23.54860394310632 | -2.506636873375909e-16 | 17.484140594533173 | 52.72640685047849
7 | 640 | 360 | 3 | 0;90;180 | -33.8619577788105 | 23.30089210171054 | 4.3422056074228343e-16 | 15.999237988264168 | 51.928664227724184
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

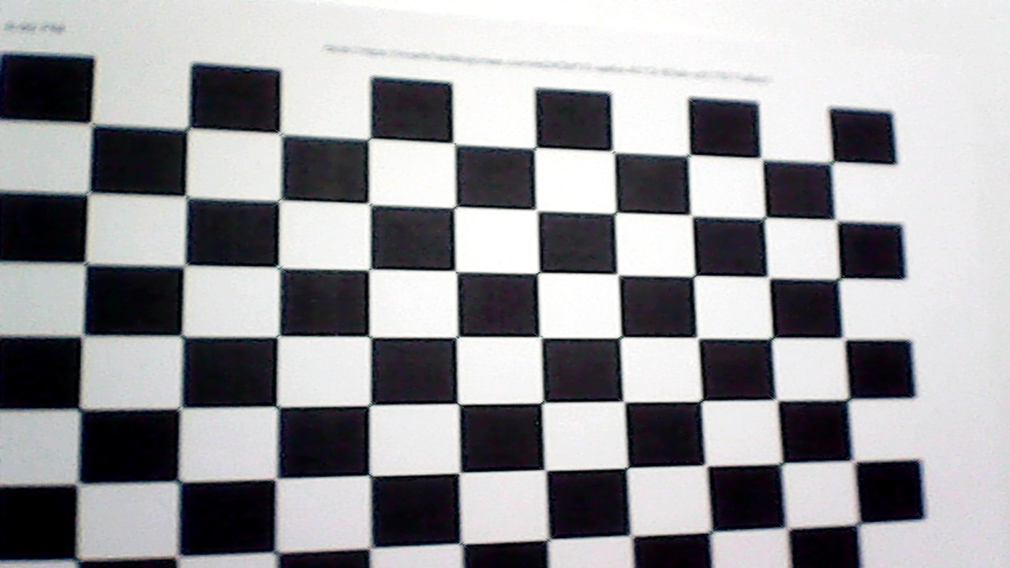
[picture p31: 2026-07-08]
calibration/calib_images_1280x720/calib_1280x720_20260707_221627_052.jpg

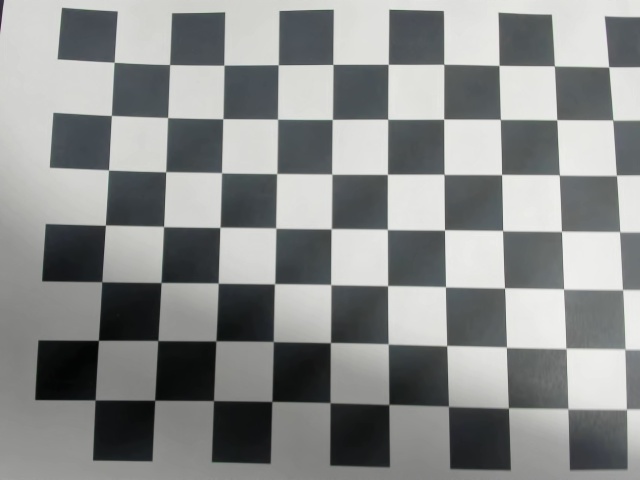
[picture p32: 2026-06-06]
calibration/calib_images/calib_058.jpg

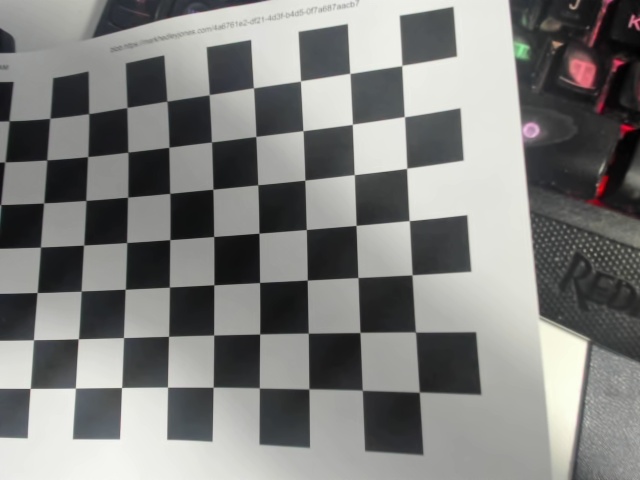
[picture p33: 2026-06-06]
calibration/calib_images/calib_004.jpg

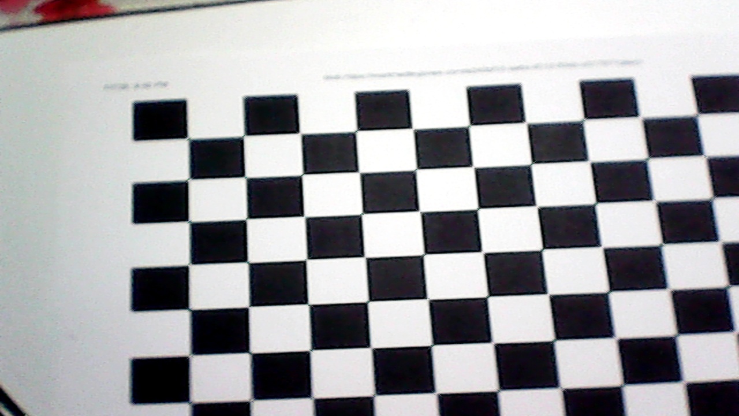
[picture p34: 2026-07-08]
calibration/calib_images_1280x720/calib_1280x720_20260707_221627_017.jpg

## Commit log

2026-05-17 Depth Image of a stationary sphere with surface normal already known
    [depth_map.ply]
2026-05-17 Bone Registration for research paper
    [paper_endoscope_a.ply, paper_endoscope_b.ply, paper_endoscope_c.ply]
2026-06-06 Camera calibration and depth testing
2026-07-08 reworked repository
    [accuracy_summary.csv, combined_CT_plus_17.ply, combined_surface.ply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]
2026-08-05 Add marker_pipeline: tracker detection, marker depth, CT distances
    Groups the tracker -> marker-depth -> CT-distance work into marker_pipeline/
    with a README manifest that marks what is reliable vs not.
    - detect_trackers.py: retroreflective marker detection (reliable)
    - marker_depth_slides.py: far-field per-shot depth + (x,y,z) slides
    - marker_distances.py: lens-to-marker distance (CT+PnP for shot_011,
    photometric+flagged for the rest)
    - apply_ct_shot011.py: CT anchor for shot_011 (diagnostic)
    - ct_correct_depth.py: affine/tilt-plane correctors (self-test passes)
    - led_calibration.py: Queau 2017 LED calibration (built, not yet used --
    needs mirror-ball + white-card captures)
    - nearfield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
2026-08-05 Add bone_depth_batch far-field core (marker-depth dependency)
    marker_pipeline/marker_depth_slides.py imports bone_depth_batch for the
    photometric-stereo solve (load_rgb, solve_luminance, photometric_stereo,
    normals_to_depth, bone_mask, balance_exposure, light_vector). Committing it so a
    fresh checkout of the marker-depth pipeline is complete.
    Change: TOP-LED azimuth 55 -> 90 deg (symmetric physical rig, matching
    nearfield_lambertian.PHYSICAL_LED_AZIMUTH_DEG); the old 55 deg was a far-field
    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
2026-08-05 Add marker-depth slides + CSV outputs
    Per-shot (x,y,z) marker-depth slides (shots 009-015), the shot_011 CT-anchored
    slide, and the data CSVs (marker_depths, marker_distances, shot_011_ct_corrected)
    from marker_pipeline. Depth values are far-field/relative (see README caveats:
    inverted vs CT at shot_011); marker locations and the shot_011 CT distances are
    the trustworthy parts.
    [marker_depths.csv, marker_distances.csv, shot_011_ct_corrected.csv]
